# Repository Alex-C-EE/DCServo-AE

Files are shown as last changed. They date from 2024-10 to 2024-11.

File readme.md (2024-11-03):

<div align="center">

# DCServo AE



[]()

**Transform any Brushed DC motor into a high-precision smart servo**

[Features](#features) • [Getting Started](#getting-started) • [Documentation](#documentation) • [Contributing](#contributing) • [Community](#community)

DCServo AE Project Banner

</div>

## 🚨 Project Status

> **This project is currently under active development by a single person.**
>
> **⚠️ IMPORTANT:** Manufacturing anything from this repository is not recommended at this time as designs are still being validated and tested.

### 🤝 Call for Contributors
We're actively seeking contributors with expertise in:
- CAD/Mechanical Design
- Specifically needed: Casing design for shaft-mounted versions
- Hardware validation and testing

## 🎯 Project Overview

DCServo AE is an open-source platform that transforms standard Brushed DC motors into continuous smart servos with high precision control. Our focus is on delivering:

- ⚡ **High Torque** output capabilities
- 🔄 **High RPM** performance
- 📏 **Precise Positioning** through absolute encoding
- 🔌 **Plug-and-Play** implementation

### Platform Variations

All versions utilize the **STM32G0** microcontroller series, chosen for its:
- 💰 Cost-effectiveness
- ⚡ Powerful timer peripherals
- 🎮 Advanced control capabilities

| Version | Description | Status |
|---|---|---|
| High Power | For industrial applications | 🟡 In Development |
| Low Power | For hobbyist projects | 🟡 In Development |
| High Voltage | 24V+ systems | 🟢 Planning |
| Low Voltage | Battery-powered devices | 🟢 Planning |

## ✨ Core Features

### Hardware Highlights
- 🔌 **Plug and Play Integration**
  - Compatible with extended/dual axis shaft motors
  - Requires magnet mounting for absolute encoding
  - Minimal design considerations needed

- 📏 **Absolute Position Encoding**
  - Magnetic absolute encoders for precise positioning
  - No homing or recalibration needed after power loss
  - Reliable position feedback

- 🎛️ **Modular Architecture**
  - Multiple configurations available
  - Scalable from hobby to industrial applications
  - Compact form factor (as small as 12mm diameter)

### Software Features
- 🔓 **Open Source**
  - Full hardware design files
  - Complete firmware source code
  - Comprehensive documentation (WIP)

- 🎮 **Control Interfaces** (Planned)
  - CAN bus
  - UART serial
  - PWM input

## 🛠️ Getting Started

### Current Manufacturing Notes
If you wish to help test the current designs:
```
📁 /Export           - Pre-exported Gerbers for each version
🏭 JLCPCB           - Files optimized for JLCPCB manufacturing
⚠️ Manual Assembly  - Currently requires hand soldering (SMT optimization coming soon)
```

### Build Instructions

#### Hardware
1. Access design files in the `/hardware` directory
   - KiCad 8.0 format PCB and schematics
   - Separate directories for each version
   - Complete BOMs included

#### Software
1. Find firmware in the `/software` directory
   - Written in C for STM32
   - Includes all necessary drivers
   - Configuration templates provided

## 📚 Documentation

> 🚧 Documentation is currently under development

Planned documentation will cover:
- [ ] Hardware assembly guides
- [ ] Software configuration
- [ ] Control interface specifications
- [ ] Performance tuning
- [ ] Application examples

## 👥 Contributing

We welcome contributions! Here's how you can help:

1. 🐛 **Report Issues**
   - Use GitHub Issues for bugs
   - Suggest improvements
   - Request features

2. 💻 **Submit Pull Requests**
   - Hardware improvements
   - Firmware enhancements
   - Documentation updates

3. 🤝 **Join Discussions**
   - Participate in GitHub Discussions
   - Join our Discord community
   - Share your implementations

## 🌟 Similar Projects

Projects that inspired DCServo AE:

- [Mechaduino](https://hackaday.io/project/11224-mechaduino)
  - Stepper motor focus
  - Open-source architecture

- [MotCTRL](https://github.com/osannolik/MotCtrl)
  - BLDC motor controller
  - Advanced control algorithms

## 📜 License

- Hardware: [CERN Open Hardware License](LICENSE-HARDWARE)
- Software: [MIT License](LICENSE-SOFTWARE)

## 🤝 Community

> 🚧 Community platforms are being established

Future platforms will include:
- Hackaday.io project page
- Discord community
- YouTube channel for tutorials and demos

---

<div align="center">

**[Back to Top](#dcservo-ae)**

</div>

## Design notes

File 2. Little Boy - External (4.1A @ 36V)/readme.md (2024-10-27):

Little Boy with externally mounted encoder - supports many SPI absolute encoder.

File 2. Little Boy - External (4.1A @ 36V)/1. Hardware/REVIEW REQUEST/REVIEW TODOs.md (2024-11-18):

# TODO List for PCB V0.4

## Schematic Updates
- [x] Move U1 and Part Number to top of microcontroller
- [x] Add 25 MHz frequency value next to Y1
- [x] Change IC# designators to U#
- [x] Rearrange symbols to remove text/line crossings
- [x] Change microcontroller symbol and move SWD/NRST connections to the bottom left
- [x] Flip CAN RX and TX
- [x] Add Common Node Choke for CAN

## Component Changes
- [x] Upgrade ISENS resistor to 2512 package for 2W+ power dissipation at 100 mOhm
- [x] Change 22uF caps rating from 6V to 16V after the buck
- [x] Change 47uF capacitor specifications (C11 - 47uF 50V in 0805 doesn't exist)
- [x] Move RSENSE closer to driver
- [x] Add electrolytic capacitor near driver's VMOT where space permits
- [x] Move C11 further from IC1

## PCB Layout
- [x] Increase spacing between XT30 connectors to allow usage of heat shrink
- [x] Move connector description silkscreen to back side
- [x] Add pin 1 triangular designators
- [x] Add shield pad vias on encoder connector
- [x] Space out U3 traces
- [x] Add more vias near data vias
- [x] Reduce unnecessary vias covering text
- [x] Move the matched CAN trace away from nearby pad
- [x] Increase ISENS trace width for 4.1A current
- [x] Fix copper hole/teardrops near C17 by using through-hole test point as via
- [x] Reduce excessive via grids (no denser than lambda/10 of highest frequency)
- [ ] *Add ground pin to CAN connectors?*
- [x] Route CAN H/L as differential pair
- [x] Move board version next to "DCServo" text in upper right corner

## Documentation
- [ ] Disable net names on all 2D PCB images (except board dimensions)
- [x] Fix SWD text to show "vdd-gnd-gnd"
- [x] Move board date to bottom side

## 3D Model
- [x] Remove duplicate XT30 connectors floating above board

## Design Review
- [x] Rethink CAN pass-through and node management/stud length
- [x] Don't compromise manufacturability for perfect length matching (10cm tolerance ok)
- [x] Avoid placing traces between pads even if within minimum track width rules

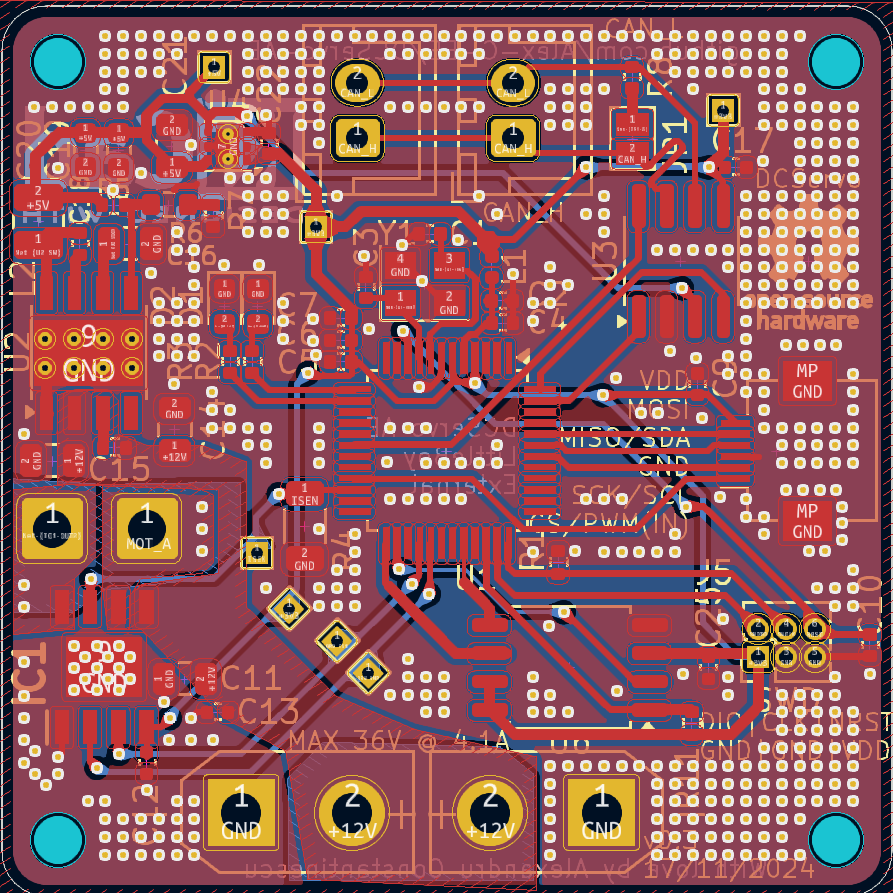
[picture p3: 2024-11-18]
2. Little Boy - External (4.1A @ 36V)/1. Hardware/REVIEW REQUEST/v0.3 17-11-24/All.png

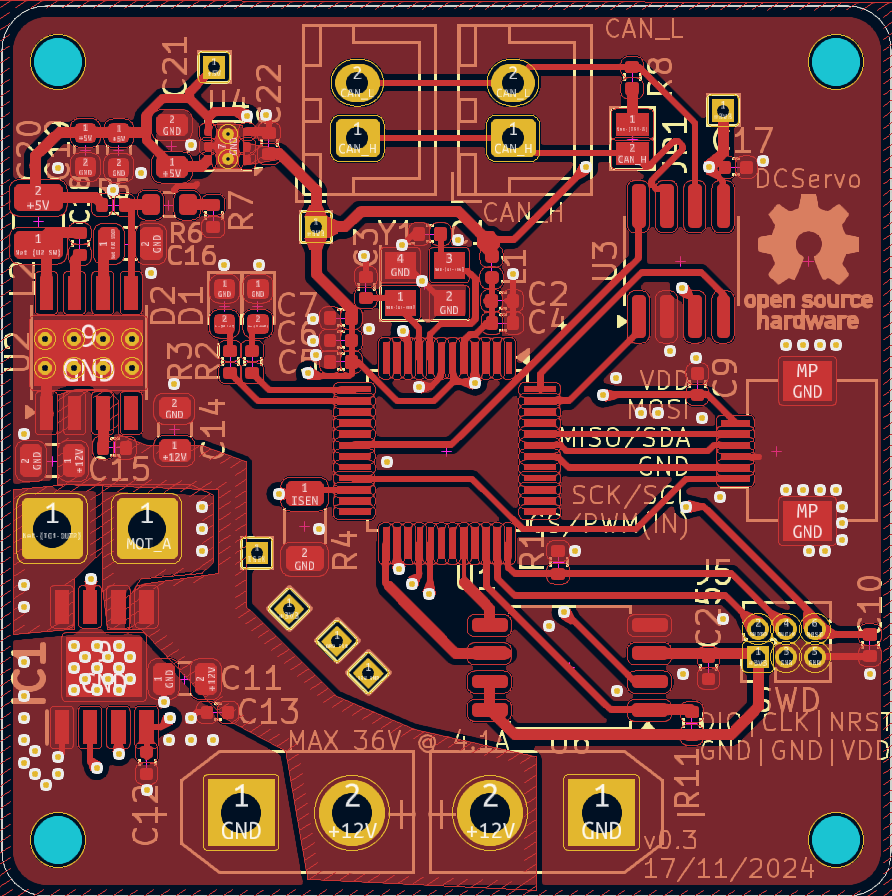
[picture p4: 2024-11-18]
2. Little Boy - External (4.1A @ 36V)/1. Hardware/REVIEW REQUEST/v0.3 17-11-24/Front.png

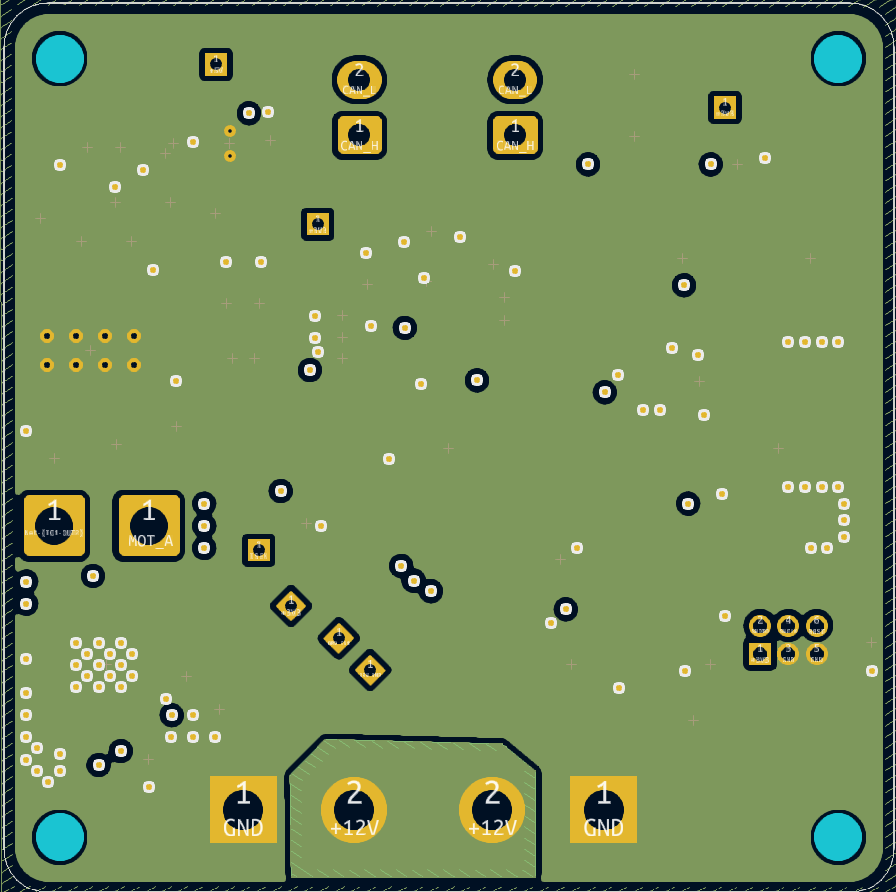
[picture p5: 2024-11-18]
2. Little Boy - External (4.1A @ 36V)/1. Hardware/REVIEW REQUEST/v0.3 17-11-24/Middle.png

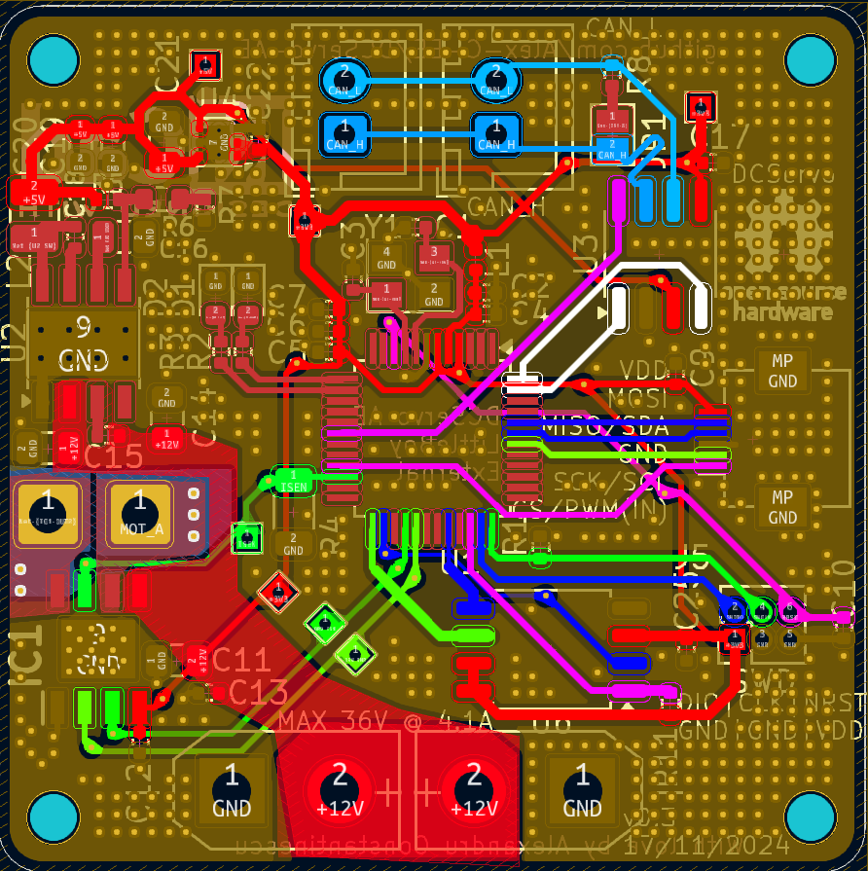
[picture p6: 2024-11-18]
2. Little Boy - External (4.1A @ 36V)/1. Hardware/REVIEW REQUEST/v0.3 17-11-24/Nets.png

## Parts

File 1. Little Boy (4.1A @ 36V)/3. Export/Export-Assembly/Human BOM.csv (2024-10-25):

Reference | Value | Footprint | Qty
C1,C11 | 100nF, X7R | -- mixed values -- | 2
C2 | 10uF, 50V, X7R | Capacitor_SMD:C_1206_3216Metric | 1
C3,C9,C10 | 100nF | Capacitor_SMD:C_0402_1005Metric | 3
C4 | 4.7uF | Capacitor_SMD:C_0402_1005Metric | 1
C5 | 1uF, X7R | Capacitor_SMD:C_0402_1005Metric | 1
C6 | 2.2uF, X7R | Capacitor_SMD:C_0402_1005Metric | 1
C7 | 10uF, 50V | Capacitor_SMD:C_1206_3216Metric | 1
C8 | 100nF, 50V | Capacitor_SMD:C_0603_1608Metric | 1
D1,D2 | LED | LED_SMD:LED_0402_1005Metric | 2
IC1 | DRV8251DDAR | _custom:SOIC127P600X170-9N | 1
R1 | 15k | Resistor_SMD:R_0402_1005Metric | 1
R2 | 120 | Capacitor_SMD:C_0402_1005Metric | 1
R3 | 10k | Resistor_SMD:R_0402_1005Metric | 1
R4,R5 | 430 | Resistor_SMD:R_0402_1005Metric | 2
U1 | LMZM23601V5 | Package_LGA:Texas_SIL0010A_MicroSiP-10-1EP_3.8x3mm_P0.6mm_EP0.7x2.9mm_ThermalVias | 1
U2 | TLV76733DRVx | Package_SON:WSON-6-1EP_2x2mm_P0.65mm_EP1x1.6mm_ThermalVias | 1
U4 | MA730 | Package_DFN_QFN:QFN-16-1EP_3x3mm_P0.5mm_EP1.75x1.75mm | 1
U5 | TJA1051T-3 | Package_SO:SOIC-8_3.9x4.9mm_P1.27mm | 1
U7 | STM32G0B1KBTx | Package_QFP:LQFP-32_7x7mm_P0.8mm | 1

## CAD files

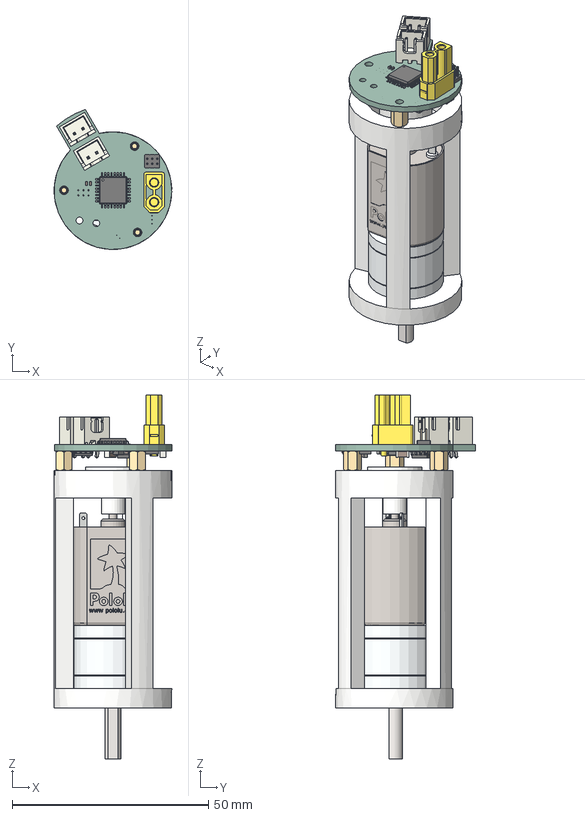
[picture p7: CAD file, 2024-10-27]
1. Little Boy (4.1A @ 36V)/4. CAD/5. CAD Assemblies/Pololu 20D/Assembly 20D v5.step
30.0 x 35.7 x 92.8 mm
Magnet
C_0402_1005Metric_1 x 6
LQFP_32_7x7mm_P08mm
JST_B2B_XH_A x 2
XT30_Buchse
PinHeader_2x03_P127mm_Vertical
C_1206_3216Metric_1 x 2
Texas_HTSOP_8_1EP_39x49mm_P127mm_EP285x49mm_Mask24x31mm_ThermalVias
WSON_6_1EP_2x2mm_P065mm_EP1x16mm
SOIC_8_39x49mm_P127mm
R_0402_1005Metric_1
C_0603_1608Metric_1
R_0603_1608Metric_1
Texas_SIL0010A_MicroSiP_10_1EP_38x3mm_P06mm_EP07x29mm
PowerServo AE 36V 3.6A 30D_PCB
20d-metal-gearmotor-25-31-with-extended-motor-shaft

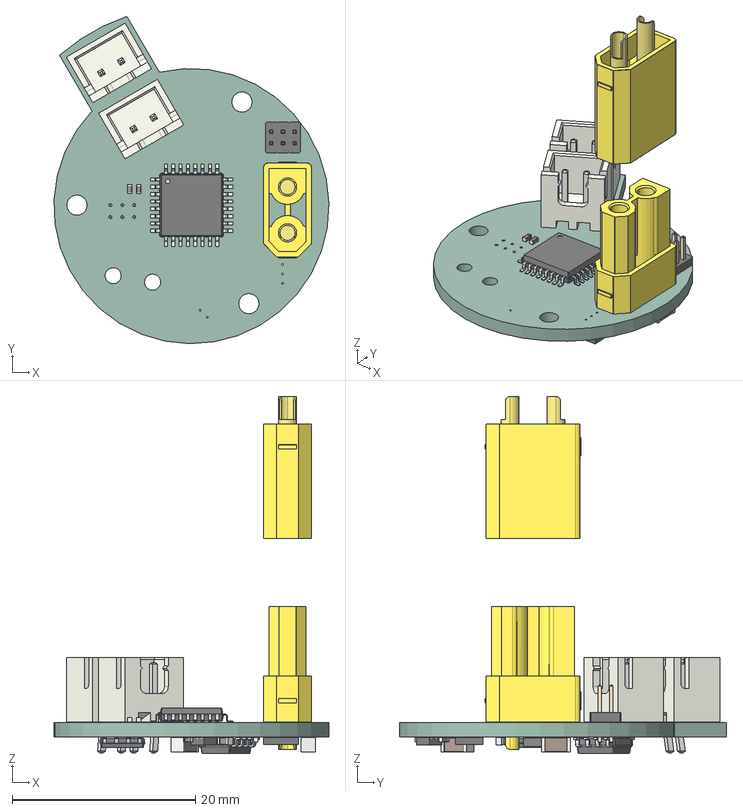
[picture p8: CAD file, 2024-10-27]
1. Little Boy (4.1A @ 36V)/4. CAD/PowerServo AE 36V 3.6A 30D CAN - CAD.step
30.0 x 35.7 x 39.0 mm
C_0402_1005Metric x 6
LQFP_32_7x7mm_P08mm
JST_B2B_XH_A x 2
XT30_Stecker
XT30_Buchse
PinHeader_2x03_P127mm_Vertical
C_1206_3216Metric x 2
Texas_HTSOP_8_1EP_39x49mm_P127mm_EP285x49mm_Mask24x31mm_ThermalVias
WSON_6_1EP_2x2mm_P065mm_EP1x16mm
SOIC_8_39x49mm_P127mm
R_0402_1005Metric
C_0603_1608Metric
R_0603_1608Metric
Texas_SIL0010A_MicroSiP_10_1EP_38x3mm_P06mm_EP07x29mm
PowerServo AE 36V 3.6A 30D_PCB

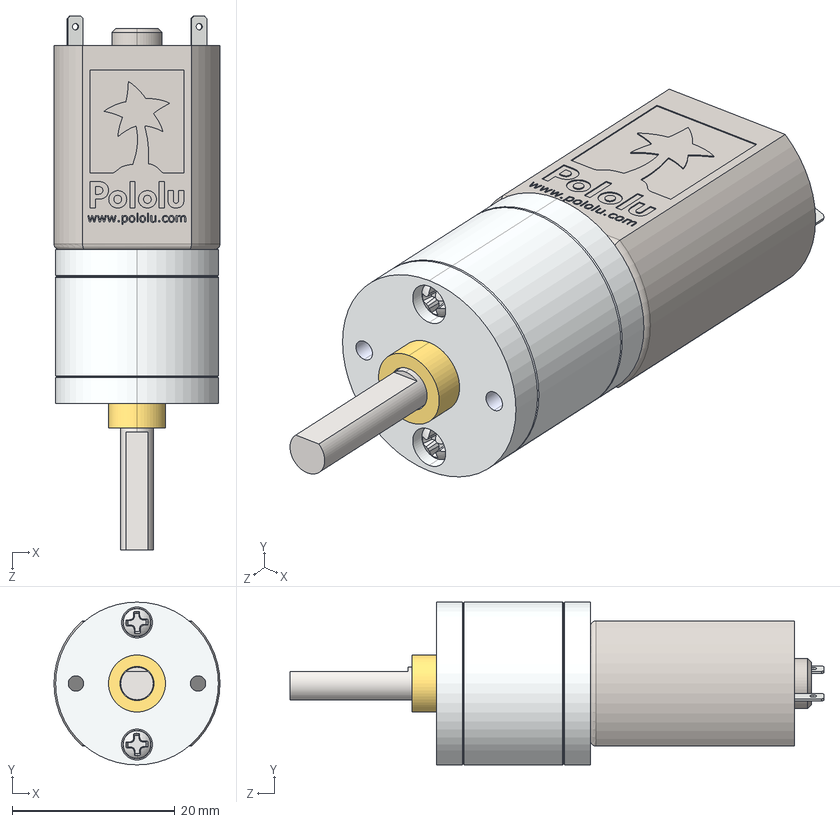
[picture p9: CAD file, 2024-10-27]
6. General CAD (motors, daughter boards, parametric casings)/Pololu 20D Motors/20d-metal-gearmotor-100-125-156-195.step
20.4 x 20.0 x 65.6 mm

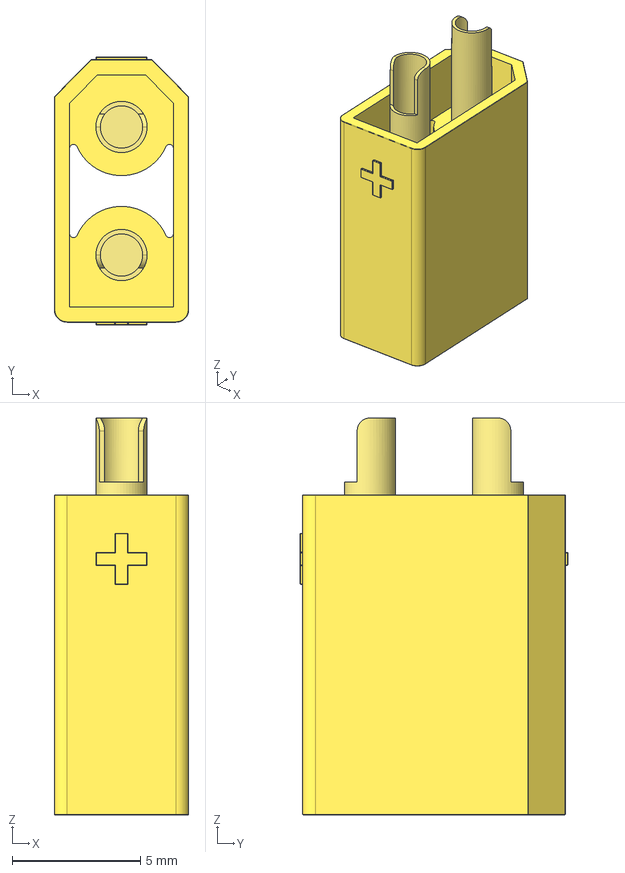
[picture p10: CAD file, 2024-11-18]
6. General CAD (motors, daughter boards, parametric casings)/XT30_Stecker.step
5.25 x 10.4 x 15.5 mm

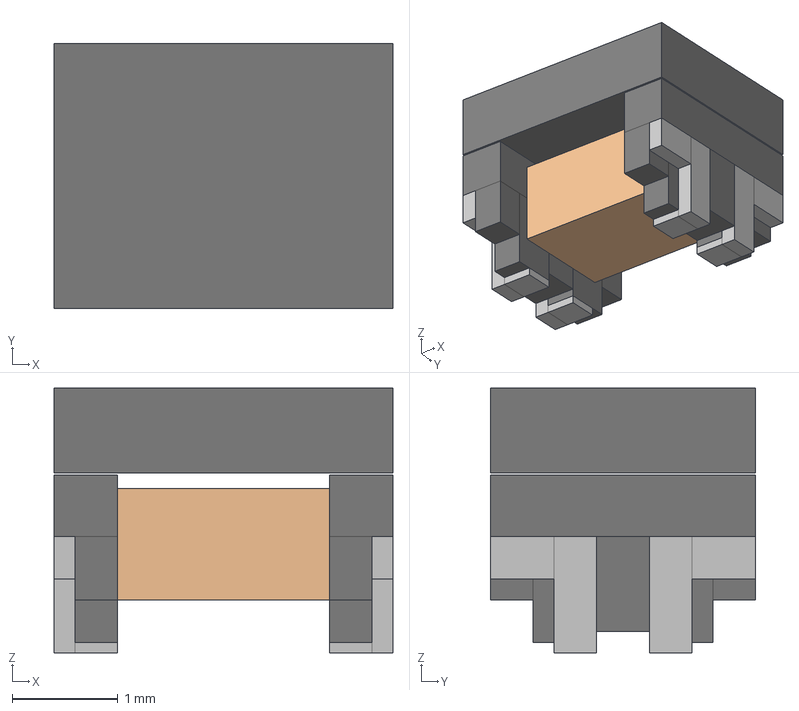
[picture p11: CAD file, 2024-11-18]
7. General Libraries/ACT1210D-101-2P-TL00 (CAN Common Mode Choke)/ACT1210D-101-2P-TL00.stp
3.20 x 2.50 x 2.50 mm
solidBody
solidC1
solidLead
solidCoil

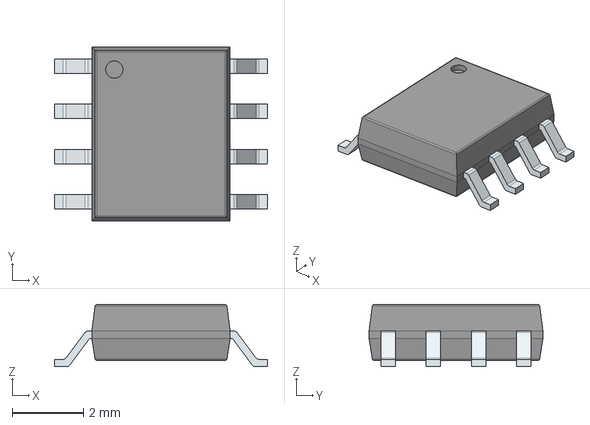
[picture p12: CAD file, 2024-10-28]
7. General Libraries/AS5600-ASOT/3D/AS5600-ASOT.stp
6.00 x 4.90 x 1.75 mm
PinsArrayLR

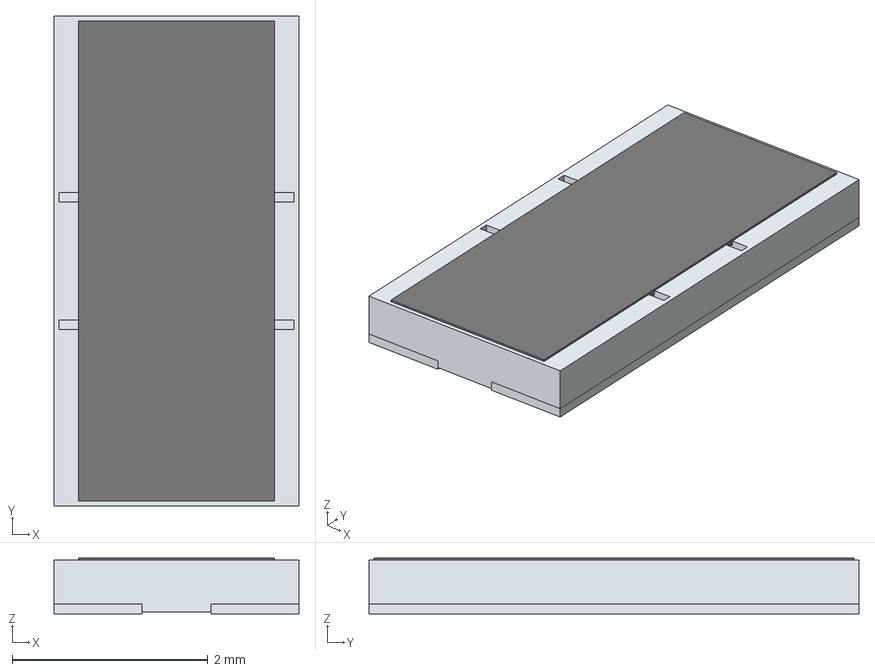
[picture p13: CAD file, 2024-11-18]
7. General Libraries/Cur Sense Res - ERJ-B1CFR/ERJ-B1CFR10U.stp
2.50 x 5.00 x 0.57 mm
solidTerminal
solidTop

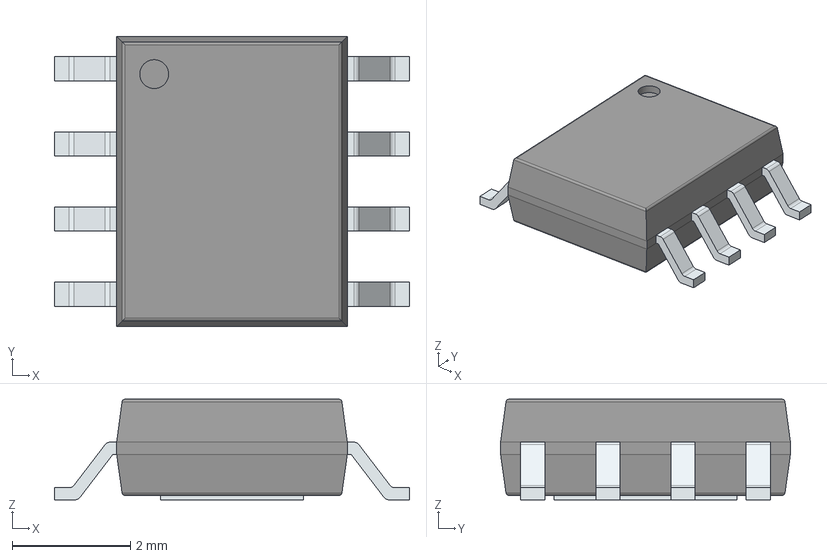
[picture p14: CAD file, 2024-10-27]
7. General Libraries/DRV8251A/DRV8251DDAR.stp
6.00 x 4.90 x 1.70 mm
PinsArrayLR
ThermalPad

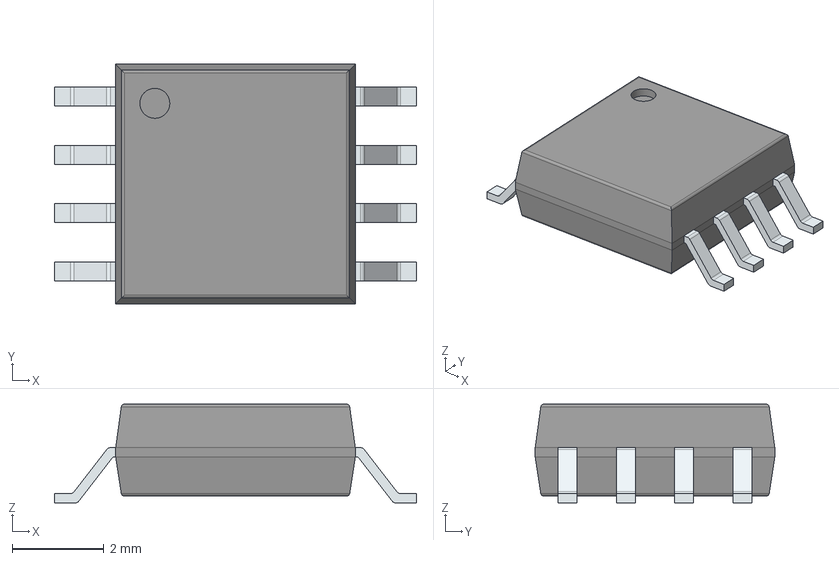
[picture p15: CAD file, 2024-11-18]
7. General Libraries/W25Q128JVSIQ/W25Q128JVSIQ.stp
7.90 x 5.23 x 2.16 mm
PinsArrayLR

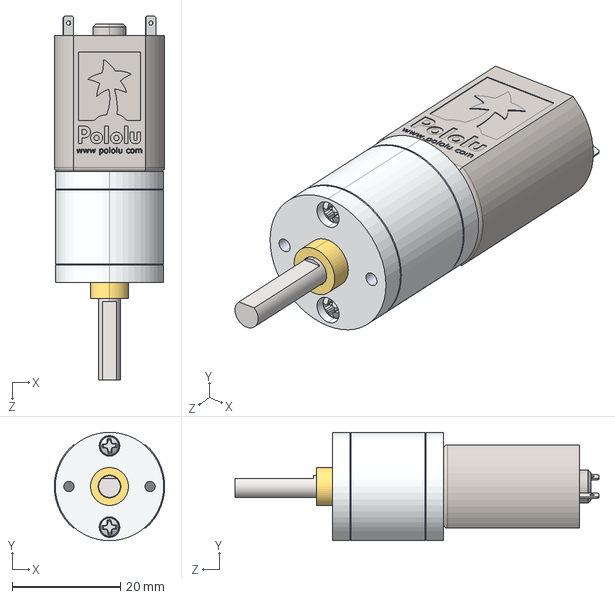
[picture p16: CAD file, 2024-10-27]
6. General CAD (motors, daughter boards, parametric casings)/Pololu 20D Motors/20d-metal-gearmotor-250-313-391-488.step
20.4 x 20.0 x 67.2 mm

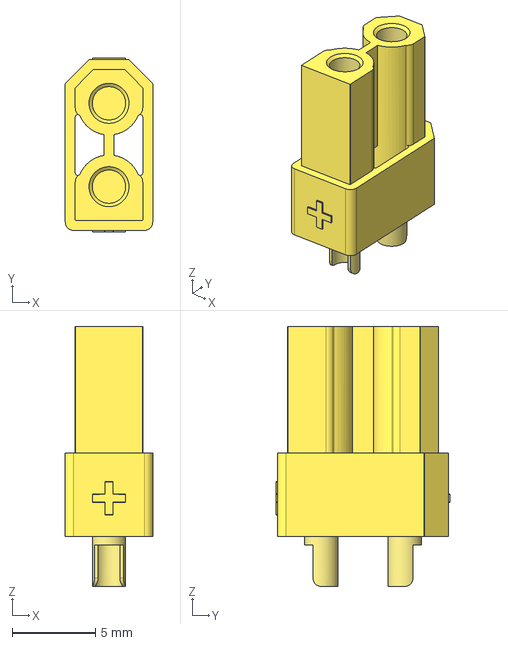
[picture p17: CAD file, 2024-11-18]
6. General CAD (motors, daughter boards, parametric casings)/XT30_Buchse (1).step
5.25 x 10.4 x 15.6 mm

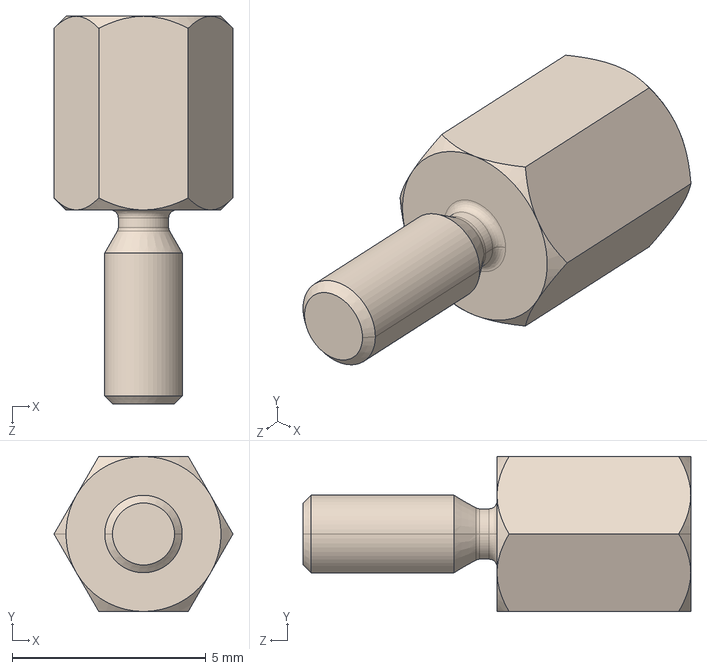
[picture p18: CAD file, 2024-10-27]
6. General CAD (motors, daughter boards, parametric casings)/Brass Stand-Off M2 x 5mm - 971050244.stp
4.62 x 4.00 x 10.00 mm

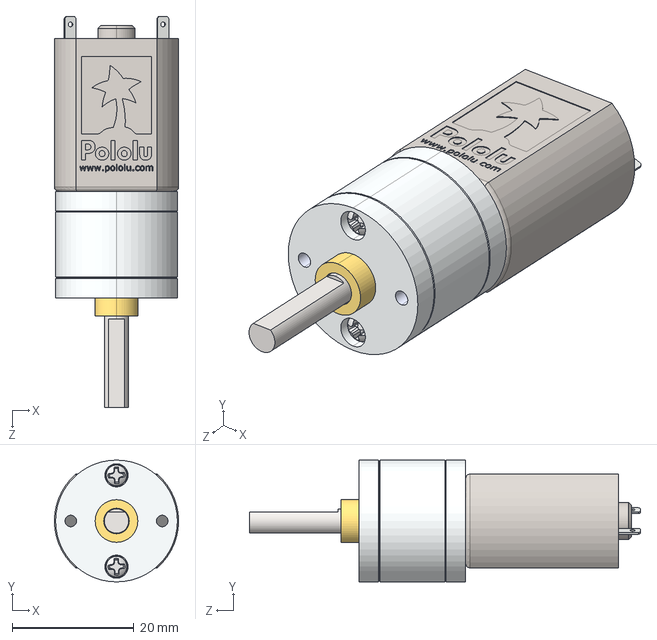
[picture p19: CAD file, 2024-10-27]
6. General CAD (motors, daughter boards, parametric casings)/Pololu 20D Motors/20d-metal-gearmotor-63-78.step
20.4 x 20.0 x 64.2 mm

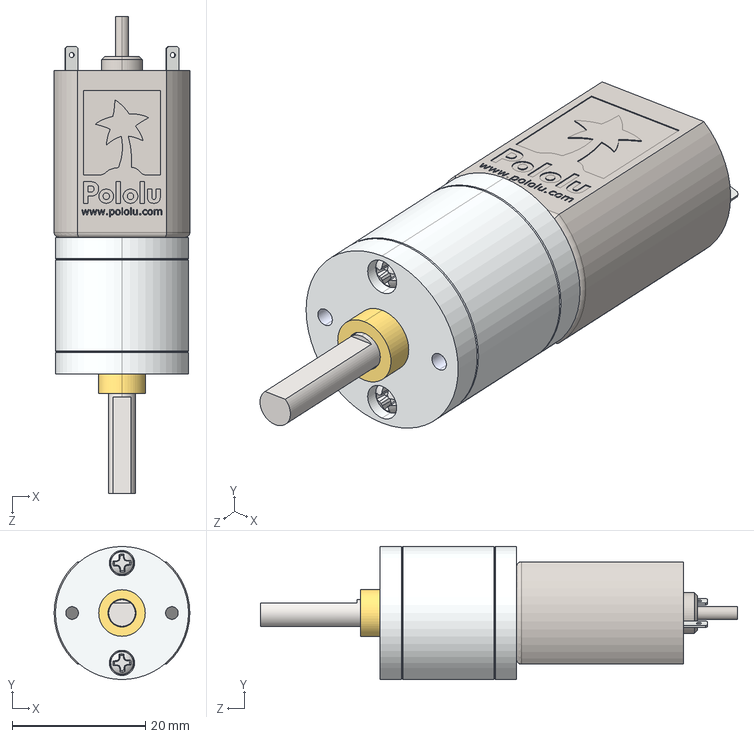
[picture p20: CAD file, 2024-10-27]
6. General CAD (motors, daughter boards, parametric casings)/Pololu 20D Motors/20d-metal-gearmotor-250-313-391-488-with-extended-motor-shaft.step
20.4 x 20.0 x 71.7 mm

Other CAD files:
6. General CAD (motors, daughter boards, parametric casings)/XT30.stp
6. General CAD (motors, daughter boards, parametric casings)/Pololu 20D Motors/20d-metal-gearmotor-63-78-with-extended-motor-shaft.step
6. General CAD (motors, daughter boards, parametric casings)/QFN-16_MA730_MNP.step
6. General CAD (motors, daughter boards, parametric casings)/Pololu 20D Motors/20d-metal-gearmotor-25-31-with-extended-motor-shaft.step
1. Little Boy (4.1A @ 36V)/3. Export/JLC PROD/SO12410236603.DXF
6. General CAD (motors, daughter boards, parametric casings)/Pololu 20D Motors/20d-metal-gearmotor-100-125-156-195-with-extended-motor-shaft.step
6. General CAD (motors, daughter boards, parametric casings)/Pololu 20D Motors/20d-metal-gearmotor-25-31.step
6. General CAD (motors, daughter boards, parametric casings)/Pololu-Micro-Metal-Gearmotor.STEP
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

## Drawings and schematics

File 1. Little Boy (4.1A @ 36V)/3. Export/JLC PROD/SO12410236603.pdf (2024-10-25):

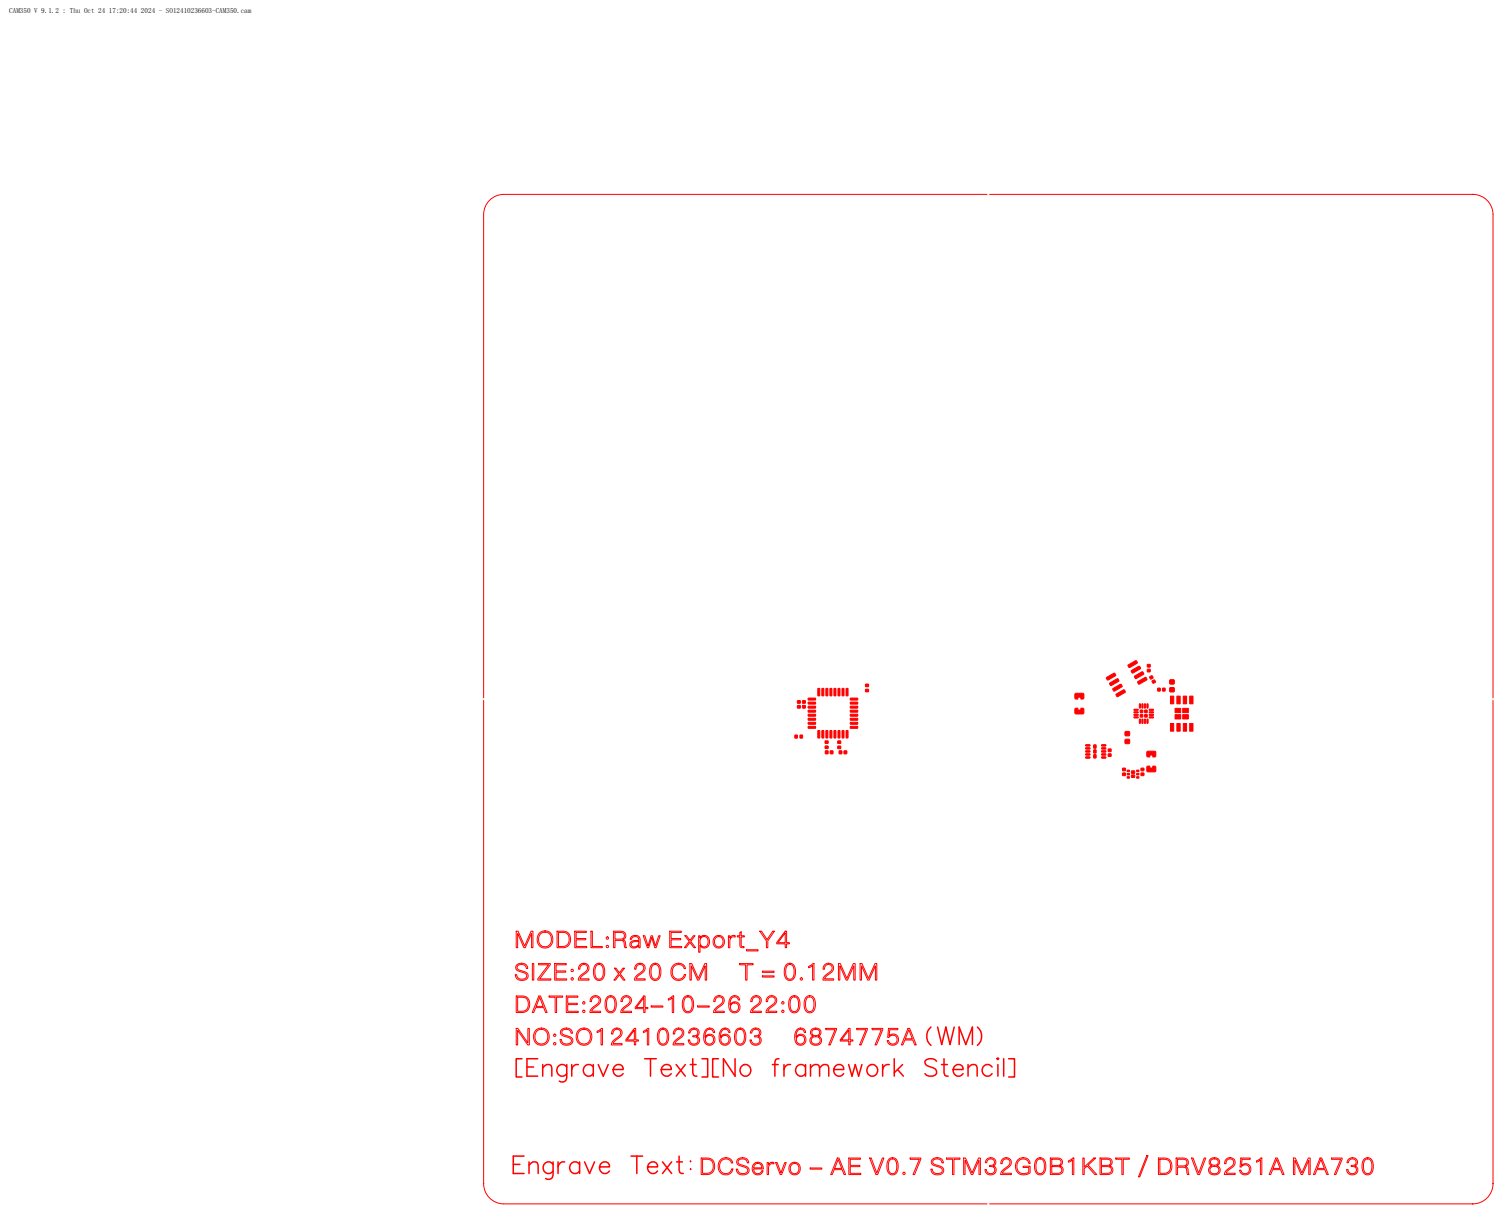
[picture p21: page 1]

CAM350 V 9.1.2 : Thu Oct 24 17:20:44 2024 - SO12410236603-CAM350.cam

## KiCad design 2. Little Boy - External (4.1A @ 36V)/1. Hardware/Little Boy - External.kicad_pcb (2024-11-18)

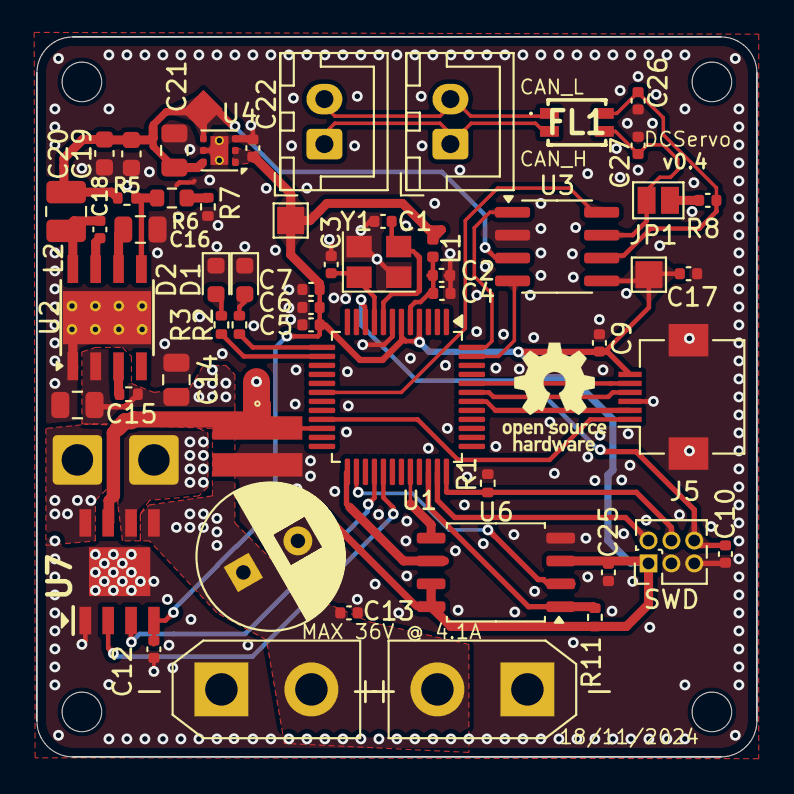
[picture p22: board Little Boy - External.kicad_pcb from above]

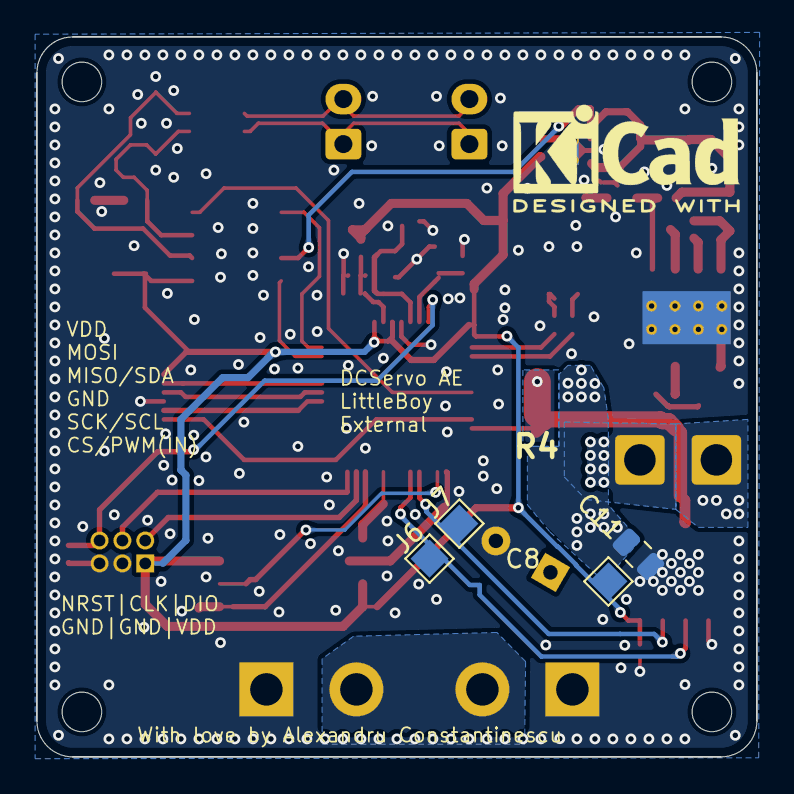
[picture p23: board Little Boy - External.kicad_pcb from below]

Board: 4 copper layers, 40.0 x 40.0 mm, 67 parts (4 on the bottom side), 41 nets.

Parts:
C1, C3: TBC; C_0402_1005Metric
C2, C5, C6, C9, C10, C17, C25: 100nF; C_0402_1005Metric
C4: 1uF; C_0402_1005Metric
C7: 4.7uF; C_0402_1005Metric
C8: 100uF, 80V; CP_Radial_D8.0mm_P3.50mm
C11, C14: 10uF, 50V; C_0805_2012Metric
C12: 100nF, X7R; C_0402_1005Metric
C13: 100nF, 50V; C_0402_1005Metric
C15: 220nF, 50V; C_0805_2012Metric
C16: 1uF, 16V, X7R; C_0805_2012Metric
C18: 100nF, 16V; C_0402_1005Metric
C19, C20: 22uF, 16V; C_0603_1608Metric
C21: 1uF, X7R; C_0805_2012Metric
C22: 2.2uF, X7R; C_0402_1005Metric
C26, C27: 100pF; C_0402_1005Metric
D1, D2: LED; LED_0603_1608Metric
FL1: ACT1210D-101-2P-TL00; ACT1210D1012PTL00
H2, H3, H6, H12: MountingHole; MountingHole_2.2mm_M2
J1, J2, J3, J6, J7, J12, J17: TESTPOINT; TestPoint_Pad_1.5x1.5mm
J5: Conn_01x06_MountingPin; Hirose_FH12-6S-0.5SH_1x06-1MP_P0.50mm_Horizontal
J8, J9: Power_In; AMASS_XT30UPB-M_1x02_P5.0mm_Vertical
J10: MOT_B; SolderWire-1sqmm_1x01_D1.4mm_OD2.7mm
J11: MOT_A; SolderWire-1sqmm_1x01_D1.4mm_OD2.7mm
J13, J14: Control_In; JST_XH_B2B-XH-A_1x02_P2.50mm_Vertical
JP1: Termination Jumper; SolderJumper-2_P1.3mm_Open_Pad1.0x1.5mm
L1: 27nH; L_0402_1005Metric
L2: 1.5 uH; L_1008_2520Metric
R1, R11: 10k; R_0402_1005Metric
R2, R3: 430; R_0402_1005Metric
R4: ERJ-B1CFR10U; ERJB1_(1020)
R5, R12: 100k; R_0402_1005Metric
R6: 24k; R_0603_1608Metric
R7: 900; R_0402_1005Metric
R8: 120; C_0402_1005Metric
SWD: Prog_IN; PinHeader_2x03_P1.27mm_Vertical
U1: STM32G0B1CBTx; LQFP-48_7x7mm_P0.5mm
U2: LMR33630CDDA; Texas_HSOP-8-1EP_3.9x4.9mm_P1.27mm_ThermalVias
U3: TJA1051T-3; SOIC-8_3.9x4.9mm_P1.27mm
U4: TLV76733DRVx; WSON-6-1EP_2x2mm_P0.65mm_EP1x1.6mm_ThermalVias
U6: W25Q128JVS; SOIC-8_5.23x5.23mm_P1.27mm
U7: DRV8251DDAR; SOIC127P600X170-9N
Y1: 25 MHz; Crystal_SMD_3225-4Pin_3.2x2.5mm

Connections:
+3.3VA: C2.1, C4.1, L1.2, U1.5 (VREF+)
+3V3: C5.1, C6.1, C7.1, C9.1, C12.2, C17.1, C22.1, C25.1, J1.1, J2.1, J3.1, J5.6, L1.1, R11.1, SWD.1, U1.4 (VBAT), U1.6 (VDD), U3.5 (VIO), U4.1 (OUT), U4.2 (SNS), U6.3 (IO2), U6.7 (IO3), U6.8 (VCC), U7.4 (VREF)
+5V: C19.1, C20.1, C21.1, J12.1, L2.2, R5.2, U3.3 (VCC), U4.4 (EN), U4.6 (IN)
+12V: C8.1, C11.2, C13.2, C14.1, C15.1, J8.2, J9.2, R12.2, U2.2 (VIN), U7.5 (VM)
CAN_H: C27.1, FL1.3, JP1.2 (B), U3.7 (CANH)
CAN_L: C26.2, FL1.4, R8.2, U3.6 (CANL)
CAN_SILENT: U1.18 (PA7), U3.8 (S)
DRV_IN1: J7.1, U1.28 (PA8), U7.3 (IN1)
DRV_IN2: J6.1, U1.29 (PA9/UCPD1_DBCC1), U7.2 (IN2)
FLASH_CLK: U1.25 (PB13), U6.6 (CLK)
FLASH_CS: R11.2, U1.34 (PA12/PA10), U6.1 (~CS)
FLASH_MISO: U1.26 (PB14), U6.2 (DO(IO1))
FLASH_MOSI: U1.32 (PA10/UCPD1_DBCC2), U6.5 (DI(IO0))
GND: C1.2, C2.2, C3.2, C4.2, C5.2, C6.2, C7.2, C8.2, C9.2, C10.1, C11.1, C12.1, C13.1, C14.2, C15.2, C16.2, C17.2, C19.2, C20.2, C21.2, C22.2, C25.2, C26.1, C27.2, D1.1, D2.1, J5.3, J5.MP (MountPin), J8.1, J9.1, R1.2, R4.2, R7.1, SWD.3, SWD.5, U1.7 (VSS), U2.1 (GND), U2.9 (GND), U3.2 (GND), U4.3 (GND), U4.5 (GND), U4.7 (PAD), U6.4 (GND), U7.1 (GND), U7.9 (THERMAL_PAD), Y1.2, Y1.4
ISEN: J17.1, R4.1, U1.22 (PB10), U7.7 (ISEN)
MAG_CS: J5.1, U1.21 (PB2)
MISO: J5.4, U1.43 (PB4)
MOSI: J5.5, U1.44 (PB5)
NRST: C10.2, SWD.6, U1.10 (PF2)
unnamed: D1.2, R2.2
unnamed: D2.2, R3.2
unnamed: J10.2, U7.8 (OUT2)
unnamed: J11.1, U7.6 (OUT1)
unnamed: FL1.2, J13.1, J14.1
unnamed: FL1.1, J13.2, J14.2
unnamed: JP1.1 (A), R8.1
unnamed: R6.1, R7.2
unnamed: R2.1, U1.13 (PA2)
unnamed: R3.1, U1.14 (PA3)
unnamed: C1.1, U1.8 (PF0), Y1.3
unnamed: C3.1, U1.9 (PF1), Y1.1
unnamed: C18.1, U2.7 (BOOT)
unnamed: R12.1, U2.3 (EN)
unnamed: R5.1, R6.2, U2.5 (FB)
unnamed: C18.2, L2.1, U2.8 (SW)
unnamed: C16.1, U2.6 (VCC)
RP_RX: U1.47 (PB8), U3.4 (RXD)
RP_TX: U1.48 (PB9), U3.1 (TXD)
SCK: J5.2, U1.42 (PB3)
SWCLK: R1.1, SWD.4, U1.36 (PA14)
SWDIO: SWD.2, U1.35 (PA13)

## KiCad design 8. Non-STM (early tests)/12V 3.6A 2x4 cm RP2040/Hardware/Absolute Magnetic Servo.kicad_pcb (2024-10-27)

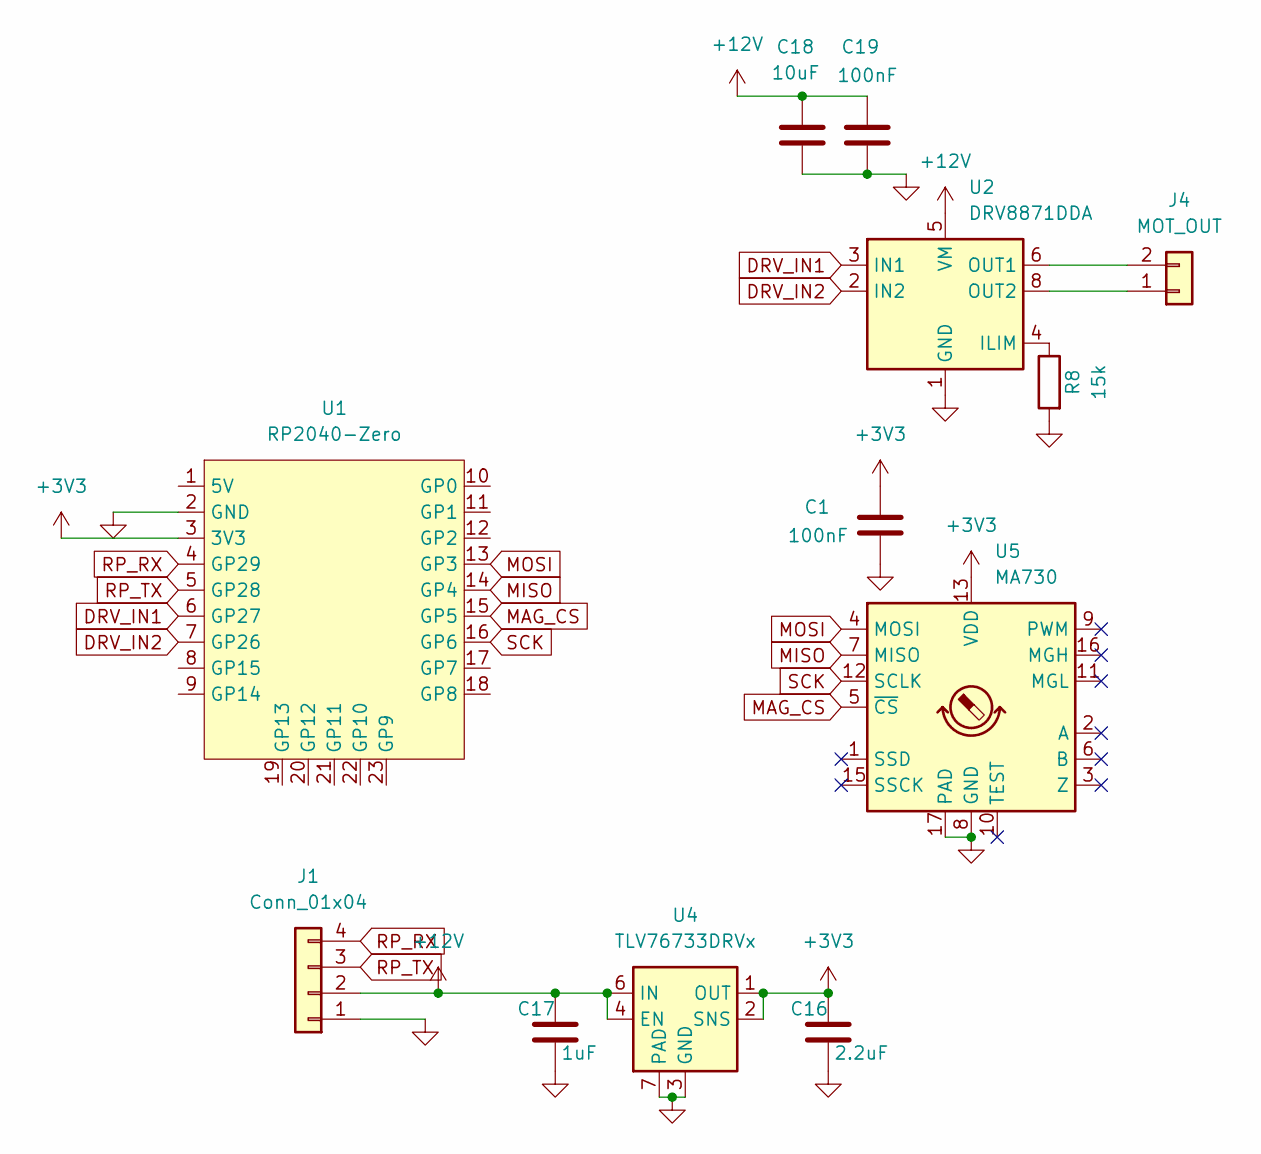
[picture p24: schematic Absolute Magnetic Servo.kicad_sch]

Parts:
C1, C19: 100nF; C_0402_1005Metric
C16: 2.2uF; C_0402_1005Metric
C17: 1uF; C_0402_1005Metric
C18: 10uF; C_0402_1005Metric
J1: Conn_01x04; JST_XH_B4B-XH-AM_1x04_P2.50mm_Vertical
J4: MOT_OUT; PinHeader_1x02_P2.54mm_Vertical
R8: 15k; R_0402_1005Metric
U1: RP2040-Zero; RP2040 Zero
U2: DRV8871DDA; Texas_HTSOP-8-1EP_3.9x4.9mm_P1.27mm_EP2.95x4.9mm_Mask2.4x3.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
U4: TLV76733DRVx; WSON-6-1EP_2x2mm_P0.65mm_EP1x1.6mm_ThermalVias
U5: MA730; QFN-16-1EP_3x3mm_P0.5mm_EP1.75x1.75mm

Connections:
+3V3: C1.2, C16.1, U1.3 (3V3), U4.1 (OUT), U4.2 (SNS), U5.13 (VDD)
+12V: C17.1, C18.2, C19.2, J1.2, U2.5 (VM), U4.4 (EN), U4.6 (IN)
DRV_IN1: U1.6 (GP27), U2.3 (IN1)
DRV_IN2: U1.7 (GP26), U2.2 (IN2)
GND: C1.1, C16.2, C17.2, C18.1, C19.1, J1.1, R8.2, U1.2 (GND), U2.1 (GND), U2.7 (GND), U2.9 (GND), U4.3 (GND), U4.5 (GND), U4.7 (PAD), U5.8 (GND), U5.17 (PAD)
MAG_CS: U1.15 (GP5), U5.5 (~CS)
MISO: U1.14 (GP4), U5.7 (MISO)
MOSI: U1.13 (GP3), U5.4 (MOSI)
unnamed: J4.1, U2.8 (OUT2)
unnamed: J4.2, U2.6 (OUT1)
unnamed: R8.1, U2.4 (ILIM)
RP_RX: J1.4, U1.4 (GP29)
RP_TX: J1.3, U1.5 (GP28)
SCK: U1.16 (GP6), U5.12 (SCLK)

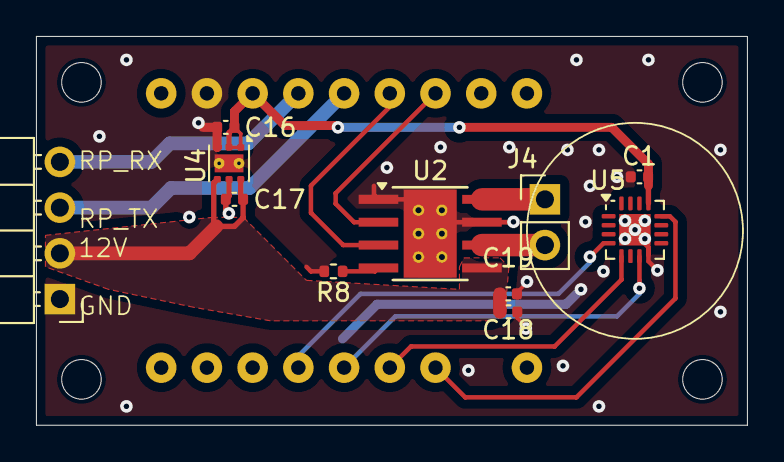
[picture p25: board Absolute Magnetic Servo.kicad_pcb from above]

Board: 4 copper layers, 39.5 x 21.6 mm, 12 parts (1 on the bottom side), 14 nets.

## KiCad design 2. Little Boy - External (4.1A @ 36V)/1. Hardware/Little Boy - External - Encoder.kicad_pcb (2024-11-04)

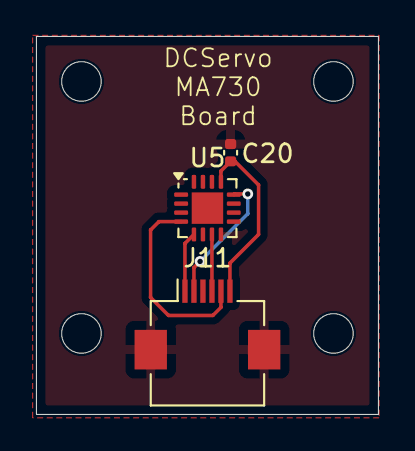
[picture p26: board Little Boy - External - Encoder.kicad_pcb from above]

Board: 4 copper layers, 19.0 x 21.0 mm, 7 parts (0 on the bottom side), 6 nets.

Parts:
C20: 100nF; C_0402_1005Metric
H2, H5, H8, H11: MountingHole; MountingHole_2.2mm_M2
J11: Conn_01x06_MountingPin; Hirose_FH12-6S-0.5SH_1x06-1MP_P0.50mm_Horizontal
U5: MA730; QFN-16-1EP_3x3mm_P0.5mm_EP1.75x1.75mm

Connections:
+3.3V: C20.2, J11.6, U5.13 (VDD)
GND1: C20.1, J11.3, J11.MP (MountPin), U5.8 (GND), U5.17 (PAD)
unnamed: J11.1, U5.5 (~CS)
unnamed: J11.2, U5.12 (SCLK)
unnamed: J11.4, U5.7 (MISO)
unnamed: J11.5, U5.4 (MOSI)

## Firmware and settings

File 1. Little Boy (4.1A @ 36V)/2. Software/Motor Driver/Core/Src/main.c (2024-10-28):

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
/* Includes ------------------------------------------------------------------*/
#include "main.h"

/* USER CODE BEGIN Includes */
#include "timers.h"
#include "motor_control.h"
#include "encoder.h"
#include "can.h"
#include "pid_controller.h"
/* USER CODE END Includes */

ADC_HandleTypeDef hadc1;

FDCAN_HandleTypeDef hfdcan2;

SPI_HandleTypeDef hspi1;

TIM_HandleTypeDef htim1;
TIM_HandleTypeDef htim2;
TIM_HandleTypeDef htim14;
TIM_HandleTypeDef htim16;

volatile uint8_t spi_rx_done = 0;
uint16_t targetAngle = 0;
uint16_t realAngle = 0;
PIDController pid;

void SystemClock_Config(void);
static void MX_GPIO_Init(void);
static void MX_SPI1_Init(void);
static void MX_FDCAN2_Init(void);
static void MX_TIM2_Init(void);
static void MX_ADC1_Init(void);
static void MX_TIM1_Init(void);
static void MX_TIM14_Init(void);
static void MX_TIM16_Init(void);
/**
  * @brief  The application entry point.
  * @retval int
  */
int main(void)
{

  /* USER CODE BEGIN 1 */

    // Assign values to the PID Controller
  pid.Kp = 1.0f;           // Proportional gain
  pid.Ki = 0.1f;           // Integral gain
  pid.Kd = 0.01f;          // Derivative gain
  pid.tau = 0.02f;         // Derivative filter time constant
  pid.limMin = -100.0f;     // Minimum output limit
  pid.limMax = 100.0f;      // Maximum output limit
  pid.T = 0.001f;            // Sample time (in seconds)

  /* USER CODE END 1 */

  /* MCU Configuration--------------------------------------------------------*/

  /* Reset of all peripherals, Initializes the Flash interface and the Systick. */
  HAL_Init();

  /* USER CODE BEGIN Init */
  CAN_INIT(0x123, FDCAN_DLC_BYTES_2);
  PIDController_Init(&pid);
  Motor_Init();
  TIMERS_Init();

  HAL_GPIO_WritePin(GPIOA, GPIO_PIN_7, GPIO_PIN_RESET); // LED 1 Off
  HAL_GPIO_WritePin(GPIOA, GPIO_PIN_4, GPIO_PIN_RESET); // LED 2 Off
  HAL_GPIO_WritePin(GPIOB, GPIO_PIN_2, GPIO_PIN_SET); // Mag CS High
  /* USER CODE END Init */

  /* Configure the system clock */
  SystemClock_Config();

  /* Initialize all configured peripherals */
  MX_GPIO_Init();
  MX_SPI1_Init();
  MX_FDCAN2_Init();
  MX_TIM2_Init();
  MX_ADC1_Init();
  MX_TIM1_Init();
  MX_TIM14_Init();
  MX_TIM16_Init();
  /* Infinite loop */
  /* USER CODE BEGIN WHILE */
  while (1){
	WATCHDOG_Reset();
	targetAngle = CAN_ProcessReceivedMessages();
  }
    /* USER CODE END WHILE */

}

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
/* USER CODE BEGIN 4 */
// Interrupt Callbacks

// SPI Interrupt callback
void HAL_SPI_RxCpltCallback(SPI_HandleTypeDef *hspi) {
    if (hspi->Instance == SPI1) { // Check if the interrupt is from SPI1
        spi_rx_done = 1; // Set the flag when data is received
        PIDController_Update(&pid, targetAngle, realAngle);
        Motor_SetDrivingValue(pid.out);
    }
}

/* USER CODE END 4 */
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


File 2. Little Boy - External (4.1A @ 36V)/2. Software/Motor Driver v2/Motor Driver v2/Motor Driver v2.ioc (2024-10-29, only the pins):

Mcu.UserName=STM32G0B1CBTx
PA13.Signal=SYS_SWDIO
PA14-BOOT0.Signal=SYS_SWCLK
PA2.Signal=GPIO_Output
PA3.Signal=GPIO_Output
PA7.GPIO_Label=GPIO_CAN_SILENT
PA7.Signal=GPIO_Output
PA8.GPIO_Label=TIM1_DRV_PWM2
PA8.Signal=S_TIM1_CH1
PA9.GPIO_Label=TIM1_DRV_PWM1
PA9.Signal=S_TIM1_CH2
PB10.GPIO_Label=ADC_ISEN
PB10.Signal=ADC1_IN11
PB2.GPIO_Label=ADC_PWM_IN / MAG_CS
PB2.Signal=ADC1_IN10
PB3.Signal=SPI3_SCK
PB4.Signal=SPI3_MISO
PB5.Signal=SPI3_MOSI
PB8.Signal=FDCAN1_RX
PB9.Signal=FDCAN1_TX

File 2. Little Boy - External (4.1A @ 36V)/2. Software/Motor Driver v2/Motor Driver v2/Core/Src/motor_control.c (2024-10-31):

/* motor_control.c */
#include "motor_control.h"
#include "main.h" // Contains handles for TIM1 and ADC1
#include <math.h> // For fabs function
#include <stdbool.h>

/* External handles from main.c */
extern ADC_HandleTypeDef hadc1;
extern TIM_HandleTypeDef htim1;

/* Configuration structure */
typedef struct {
    float brakeStrength;         // Braking power (0.0 to 1.0)
    float angleThreshold;        // Minimum angle change to consider motor stopped
    uint32_t brakeTimeout;       // Maximum braking time in milliseconds
    uint32_t angleCheckInterval; // Time between angle checks in milliseconds
} Motor_Config_t;

/* Private variables */
static float currentDutyCycle = 0.0f;
static Motor_Direction_t currentDirection = MOTOR_STOP;
static Motor_Direction_t lastDirection = MOTOR_STOP;
static bool isBraking = false;
static uint32_t brakeStartTime = 0;
static float lastAngle = 0.0f;
static uint32_t lastAngleCheckTime = 0;

/* Default configuration */
static Motor_Config_t config = {
    .brakeStrength = 0.3f,        // 30% brake strength
    .angleThreshold = 0.1f,       // 0.1 degree threshold
    .brakeTimeout = 2000,         // 2 second timeout
    .angleCheckInterval = 50      // Check angle every 50ms
};

/* Private function prototypes */
static void UpdatePWMOutputs(void);
static bool IsMotorStopped(float currentAngle);

/* Initialize motor control */
void Motor_Init(void) {
    // Start TIM1 PWM channels
    HAL_TIM_PWM_Start(&htim1, TIM_CHANNEL_1);  // Forward channel
    HAL_TIM_PWM_Start(&htim1, TIM_CHANNEL_2);  // Backward channel

    // Enable ADC watchdog on channel 11
    HAL_ADC_Start_IT(&hadc1);

    // Set initial state
    Motor_Stop();
}

/* Configure motor parameters */
void Motor_Configure(float brakeStrength, float angleThreshold,
                    uint32_t brakeTimeout, uint32_t angleCheckInterval) {
    config.brakeStrength = fmaxf(0.0f, fminf(brakeStrength, 1.0f));
    config.angleThreshold = angleThreshold;
    config.brakeTimeout = brakeTimeout;
    config.angleCheckInterval = angleCheckInterval;
}

/* Set motor speed directly from PID output */
void Motor_SetSpeed(double pidOutput) {
    // Store last direction before changing it
    lastDirection = currentDirection;

    // PID output is already clamped to ±100%
    float drivingValue = (float)pidOutput;

    // Determine direction based on polarity
    if (drivingValue > 0.0f) {
        currentDirection = MOTOR_FORWARD;
    } else if (drivingValue < 0.0f) {
        currentDirection = MOTOR_BACKWARD;
    } else {
        currentDirection = MOTOR_STOP;
    }

    // Convert to duty cycle (0.0 to 1.0)
    currentDutyCycle = fabs(drivingValue) / 100.0f;
    isBraking = false;  // Clear braking flag when setting new speed

    UpdatePWMOutputs();
}

/* Emergency stop without braking */
void Motor_Stop(void) {
    lastDirection = currentDirection;
    currentDutyCycle = 0.0f;
    currentDirection = MOTOR_STOP;
    isBraking = false;
    UpdatePWMOutputs();
}

/* Dynamic braking */
void Motor_Brake(void) {
    if (!isBraking) {
        // Initialize braking
        lastDirection = currentDirection;
        brakeStartTime = HAL_GetTick();
        isBraking = true;
        lastAngleCheckTime = brakeStartTime;

        // Apply reverse current based on last direction
        currentDutyCycle = config.brakeStrength;
        currentDirection = (lastDirection == MOTOR_FORWARD) ? MOTOR_BACKWARD : MOTOR_FORWARD;

        UpdatePWMOutputs();
    }
}

/* Update braking state - should be called in main loop */
void Motor_UpdateBraking(float currentAngle) {
    if (!isBraking) {
        return;
    }

    uint32_t currentTime = HAL_GetTick();

    // Check if it's time to measure angle change
    if (currentTime - lastAngleCheckTime >= config.angleCheckInterval) {
        if (IsMotorStopped(currentAngle) ||
            (currentTime - brakeStartTime >= config.brakeTimeout)) {
            // Motor has stopped or timeout reached - end braking
            Motor_Stop();
            return;
        }

        // Update last angle for next check
        lastAngle = currentAngle;
        lastAngleCheckTime = currentTime;
    }
}

/* Private: Check if motor has effectively stopped */
static bool IsMotorStopped(float currentAngle) {
    float angleChange = fabs(currentAngle - lastAngle);
    return angleChange < config.angleThreshold;
}

/* Get current from DRV8251 current sense output */
float Motor_GetCurrent(void) {
    // Start ADC conversion
    HAL_ADC_Start(&hadc1);

    if (HAL_ADC_PollForConversion(&hadc1, 10) == HAL_OK) {
        uint32_t adcValue = HAL_ADC_GetValue(&hadc1);

        // DRV8251 current sense conversion
        // Assuming 3.3V reference and 12-bit ADC
        float voltage = (adcValue / 4095.0f) * 3.3f;

        // Convert voltage to current based on DRV8251 specs
        float current = voltage / 0.5f; // Adjust ratio as needed

        return current;
    }

    return -1.0f; // Error case
}

/* Private: Update PWM outputs */
static void UpdatePWMOutputs(void) {
    uint32_t period = __HAL_TIM_GET_AUTORELOAD(&htim1);
    uint32_t pulseValue = (uint32_t)(currentDutyCycle * period);

    switch (currentDirection) {
        case MOTOR_FORWARD:
            // For forward: CH1 active, CH2 inactive
            __HAL_TIM_SET_COMPARE(&htim1, TIM_CHANNEL_1, pulseValue);
            __HAL_TIM_SET_COMPARE(&htim1, TIM_CHANNEL_2, 0);
            break;

        case MOTOR_BACKWARD:
            // For backward: CH2 active, CH1 inactive
            __HAL_TIM_SET_COMPARE(&htim1, TIM_CHANNEL_1, 0);
            __HAL_TIM_SET_COMPARE(&htim1, TIM_CHANNEL_2, pulseValue);
            break;

        case MOTOR_STOP:
        default:
            // Stop motor by setting both channels to 0
            __HAL_TIM_SET_COMPARE(&htim1, TIM_CHANNEL_1, 0);
            __HAL_TIM_SET_COMPARE(&htim1, TIM_CHANNEL_2, 0);
            break;
    }
}

/* ADC Watchdog callback for overcurrent protection */
void HAL_ADC_LevelOutOfWindowCallback(ADC_HandleTypeDef *hadc) {
    if (hadc->Instance == ADC1) {
        // Overcurrent detected - emergency stop
        Motor_Stop();
        // Report error over CAN
        CAN_Log_Now("ERR:OVERCURRENT");
    }
}

/* Get current brake status */
bool Motor_IsBraking(void) {
    return isBraking;
}

/* Get last known direction */
Motor_Direction_t Motor_GetLastDirection(void) {
    return lastDirection;
}

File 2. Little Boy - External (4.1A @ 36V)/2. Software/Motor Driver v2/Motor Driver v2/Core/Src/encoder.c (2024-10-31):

/* encoder.c */
#include "main.h"
#include "config.h"

// Define constants
#define CS_PIN GPIO_PIN_4        // Change this to your CS pin
#define CS_PORT GPIOA            // Change this to your GPIO port for CS
#define FIELD_ERROR_CHECK_DELAY_MS 100  // How often to check field strength in milliseconds

extern SPI_HandleTypeDef hspi1;         // Assuming you are using SPI1, adjust if different

// Define a variable to store the received data
static volatile uint16_t spi_rx_buffer = 0;
extern volatile uint8_t spi_rx_done;    // Flag to indicate SPI data received

static double prevAngle = 0.0;
static uint32_t prevTime = 0;
static const double VELOCITY_FILTER_ALPHA = 0.2;  // Adjustable filter constant

// Function prototypes
static double ConvertRawToDegrees(uint16_t raw_value);
static uint16_t SwapBytes(uint16_t val);
void Encoder_Init(void);
static HAL_StatusTypeDef Encoder_ReadRegister(uint8_t reg_addr, uint16_t *value);
static HAL_StatusTypeDef Encoder_WriteRegister(uint8_t reg_addr, uint16_t value);
void Update_Encoder_Angle(void);
void Encoder_SetZero(void);
void CheckMagneticField(void);

// Function to convert raw SPI data to degrees
static double ConvertRawToDegrees(uint16_t raw_value) {
    // The MA730 uses 14-bit resolution, mask out unused bits
    raw_value &= 0x3FFF;  // Mask to keep only the 14 relevant bits
    // Convert the 14-bit raw value into degrees
    return ((double)raw_value / 16384.0) * 360.0;
}

// Helper function to swap bytes (big-endian to little-endian or vice versa)
static uint16_t SwapBytes(uint16_t val) {
    return (val << 8) | (val >> 8);
}

// Function to initialize encoder parameters
void Encoder_Init(void) {
    // Verify that the encoder is configured for SPI communication
    if (config.encoderComm != ENCODER_COMM_SPI) {
        // Handle incorrect configuration
        Error_Handler();
    }

    // Initialize GPIO for CS pin if needed
    // Example: Configure CS pin as output
    GPIO_InitTypeDef GPIO_InitStruct = {0};
    GPIO_InitStruct.Pin = CS_PIN;
    GPIO_InitStruct.Mode = GPIO_MODE_OUTPUT_PP;
    GPIO_InitStruct.Pull = GPIO_NOPULL;
    GPIO_InitStruct.Speed = GPIO_SPEED_FREQ_LOW;
    HAL_GPIO_Init(CS_PORT, &GPIO_InitStruct);

    // Ensure CS is high (inactive) after initialization
    HAL_GPIO_WritePin(CS_PORT, CS_PIN, GPIO_PIN_SET);
}

// Helper function to read a 16-bit register from the encoder
static HAL_StatusTypeDef Encoder_ReadRegister(uint8_t reg_addr, uint16_t *value) {
    uint8_t read_cmd = 0x40 | (reg_addr & 0x3F);  // Assuming 0x40 is the read command base
    uint8_t rx_buffer[2] = {0};

    // Pull CS low to select the MA730
    HAL_GPIO_WritePin(CS_PORT, CS_PIN, GPIO_PIN_RESET);

    // Transmit the read command
    if (HAL_SPI_Transmit(&hspi1, &read_cmd, 1, HAL_MAX_DELAY) != HAL_OK) {
        HAL_GPIO_WritePin(CS_PORT, CS_PIN, GPIO_PIN_SET);
        return HAL_ERROR;
    }

    // Receive the 16-bit register value
    if (HAL_SPI_Receive(&hspi1, rx_buffer, 2, HAL_MAX_DELAY) != HAL_OK) {
        HAL_GPIO_WritePin(CS_PORT, CS_PIN, GPIO_PIN_SET);
        return HAL_ERROR;
    }

    // Pull CS high to release the MA730
    HAL_GPIO_WritePin(CS_PORT, CS_PIN, GPIO_PIN_SET);

    // Combine received bytes into a 16-bit value (assuming big-endian)
    *value = (rx_buffer[0] << 8) | rx_buffer[1];
    *value = SwapBytes(*value);  // Swap bytes if necessary based on SPI configuration

    return HAL_OK;
}

double Encoder_CalculateVelocity(void) {
    uint32_t currentTime = HAL_GetTick();
    uint32_t deltaTime = currentTime - prevTime;

    if (deltaTime < 1) {  // Prevent division by zero
        return config.currentVelocity;
    }

    double deltaAngle = config.currentAngle - prevAngle;

    // Handle angle wrapping
    if (deltaAngle > 180.0) {
        deltaAngle -= 360.0;
    } else if (deltaAngle < -180.0) {
        deltaAngle += 360.0;
    }

    // Calculate instantaneous velocity in degrees per second
    double instantVelocity = (deltaAngle * 1000.0) / deltaTime;  // Convert ms to seconds

    // Apply low-pass filter
    config.currentVelocity = (VELOCITY_FILTER_ALPHA * instantVelocity) +
                            ((1.0 - VELOCITY_FILTER_ALPHA) * config.currentVelocity);

    // Update previous values
    prevAngle = config.currentAngle;
    prevTime = currentTime;

    return config.currentVelocity;
}

// Helper function to write a 16-bit register to the encoder
static HAL_StatusTypeDef Encoder_WriteRegister(uint8_t reg_addr, uint16_t value) {
    uint8_t write_cmd = 0x20 | (reg_addr & 0x3F);  // Assuming 0x20 is the write command base
    uint16_t swapped_value = SwapBytes(value);
    uint8_t tx_buffer[3] = {
        write_cmd,
        (swapped_value >> 8) & 0xFF,  // High byte
        swapped_value & 0xFF          // Low byte
    };

    // Pull CS low to select the MA730
    HAL_GPIO_WritePin(CS_PORT, CS_PIN, GPIO_PIN_RESET);

    // Transmit the write command and data
    if (HAL_SPI_Transmit(&hspi1, tx_buffer, 3, HAL_MAX_DELAY) != HAL_OK) {
        HAL_GPIO_WritePin(CS_PORT, CS_PIN, GPIO_PIN_SET);
        return HAL_ERROR;
    }

    // Pull CS high to release the MA730
    HAL_GPIO_WritePin(CS_PORT, CS_PIN, GPIO_PIN_SET);

    return HAL_OK;
}

// Function to read MA730 data over SPI and update config
void Update_Encoder_Angle(void) {
    uint16_t angle_raw = 0;

    // Read the angle register (assuming register 0x00 contains the angle)
    if (Encoder_ReadRegister(0x00, &angle_raw) != HAL_OK) {
        // Handle read error
        Error_Handler();
    }

    // Convert the raw value to degrees and update the config structure
    config.currentAngle = ConvertRawToDegrees(angle_raw);

    // Calculate and update velocity
    Encoder_CalculateVelocity();
}
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

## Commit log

2024-10-25 Fixed driver error
    [PowerServo AE 36V 3.6A 30D.kicad_pcb]
2024-10-27 Restructured the Project to make it have more sense. Dropped UART, PWM plans.
    [20d-metal-gearmotor-100-125-156-195-with-extended-motor-shaft.step, 20d-metal-gearmotor-100-125-156-195.step, 20d-metal-gearmotor-25-31-with-extended-motor-sha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]
2024-10-27 More organizing
    [36V 10A.kicad_pcb, 36V 10A.kicad_sch]
2024-10-27 More organizing, expanded scope
    [20d-metal-gearmotor-100-125-156-195-with-extended-motor-shaft.step, 20d-metal-gearmotor-100-125-156-195.step, 20d-metal-gearmotor-25-31-with-extended-motor-sha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]
2024-10-28 Began work on V2 through the extended version
    [AS5600-ASOT.stp, Little Boy - External.kicad_sch, PowerServo AE 36V 3.6A 30D.kicad_pcb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]
2024-10-29 V2 init commit
    [Little Boy - External.kicad_pcb, Little Boy - External.kicad_sch]
2024-10-29 Software Drop
    CAN, PID, central CONFIG
2024-10-29 Software Drop
    CAN, PID, Main config
2024-10-31 Esthetic Changes, Fix-up of daughter boards.
    [Little Boy - External.kicad_pcb, Little Boy - External.kicad_sch]
2024-11-04 V2.2 - Added Test Points, fixed DFM Errors
    [Little Boy - External - Encoder.kicad_pcb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]
2024-11-17 review request, v0.3
    [Little Boy - External.kicad_pcb, Little Boy - External.kicad_sch, W25Q128JVSIQ.stp]
2024-11-18 v0.3.5 effectively, most TODOs implemented
    [ERJ-B1CFR10U.stp, Little Boy - External.kicad_pcb, Little Boy - External.kicad_sch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]
2024-11-18 v4 full
    [Little Boy - External.kicad_pcb, Little Boy - External.kicad_sch]

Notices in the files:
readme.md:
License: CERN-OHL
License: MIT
